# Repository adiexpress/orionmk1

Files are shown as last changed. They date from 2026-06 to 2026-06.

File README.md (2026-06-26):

Hello All who come to this project

This is the beginnings of Project O.R.I.O.N, which stands for Object Retrieval and Intelligent Operating Network

Group 1-3

ORION is a robot arm system designed to assist at a workstation. Inspired by Doctor Octopus from Spider-Man, it features a flexible tendon-driven tentacle spine arm with a 3-jaw gripper, 3 wide-angle AI cameras linked together, local voice recognition, and object detection — all running fully offline on a Raspberry Pi 5 with a Raspberry Pi AI HAT+ (Hailo-8 NPU, 26 TOPS).

The hub is a wide shallow tray (Pi and HAT side by side) keeping hub height under 1.7 inches, leaving 5.8 inches of clearance above the monitors. It detaches via a quick-release plate and runs standalone on a camera tripod from a power bank.

The spine is cable-tendon driven — 3 Dyneema UHMWPE cables (65-80lb, ~0.4mm) run through PTFE-lined channels in 9 triangular PETG segments, pulled by 3 MG996R base servos for full 3D motion. Each segment is an equilateral triangle (70mm sides, 35mm body) with M4 RC rod-end ball joints alternating 90 degrees per segment. Total reach: ~19.5 inches

The sensors that are used in this project are the FSR402 pressure sensors on the tips of the fingers of the claw

This project is driven on a few AI Models: Whisper, by OpenAI for the language transcription when a user asks a question, YOLOV8 by Ultralytics for the object tracking and detection, OpenWakeWord which is the key tool behind the "Hey ORION" activation call, and LLaVA Phi 3 for the live object description in the webcam whenever a user uses the "describe" action

Orion runs on Qwen 2.5 3B parameters version by Alibaba and essentially it is the framework for all the reasoning and computing done by the model. 

The camera system runs on 3 USB 2.0 Cameras (1080P 130 degree rotation) to help with object tracking/detection and also obstacle avoidance.
After initial calibration where the cameras are trained on distict marked locations so that they can make their distance measurements, the tri-camera system uses triangulation to gather measurements from each of the 3 FOV ranges that it has. Using this, the ORION arm has almost 360 degree FOV. 

## The Problem and our motivation to create ORION
We created this project to help future engineers, like my teammate and I, strive in the workplace when no one else is there to help. 
We built ORION because we've both been there. 
Spending late nights building something extraordinary that could change the world, but it feels like building it requires three hands. 

**ORION was made to be that 3rd hand.**

ORION is the answer to that. It acts like a personal desktop assistant that can physically help you with tasks like holding up objects, putting unnecessary tools
away, or even holding up a flashlight for those dark corners you can never see into. ORION is more than just an average robotic arm, however. It can even act as a friend. With its built-in AI voice-chat feature, you can have conversations about whatever weird things you like and it can answer the most redundant of questions. 

Many of us engineers have come to the realization that the biggest bottleneck in this field isn't knowledge or skill, but rather - its bandwidth. What my partner and I needed was a third hand that doesn't need a break, never gets tired, and doesn't complain.

## We built what we needed and we hope someone like us needs it too
<br>

## Our Motivation
<br>
Most robotics projects are built in labs, with teams with almost too large of a wallet. In contrast, ORION was built with 2 people, over nights and weekends, communicating async over schedules that seemed to never overlap
<br>
That constraint became our main idea for design, ORION had to be simple enough for two people to design and also others to easily recrate, but also powerful enough to actually keep up with our quick engineering minds 
<br>
We decided to make it run offline because we could never guarantee internet, it had to run from voice because our hands were usually always full, and we had to make it cost-effective because our budget was tight.
<br>
Every decision in this project came from a real constraint we had to come across while building it, combined with our high engineering standards
<br>

## DISCLAIMER
Due to hardware deficiency, the custom "Hey ORION" wake word has not been trained yet. The system currently uses "Hey Jarvis" (a pre-trained OpenWakeWord model). Once hardware arrives, a custom model will be trained using OpenWakeWord's training pipeline and swapped in with a single config change.
<br>

## How the pipeline works:

1. Orion starts up and greets the user
2. Orion asks the user for the wake word (in this case it will be "Hey Jarvis")
3. The user either speaks the wake word or waits until they require the assistance of Orion
4. After receiving the wake word, Orion then asks the user for a command from which they have a few preset options to choose from:
   - grab: grabs an object that must be specified by the user
   - move to: moves an object that must be specified by the user to a location
   - drop: drops the object the arm is holding in the position it is currently at
   - stow: puts the arm away into "sleep mode"
   - describe: describes the object that is in the webcam's POV
   - clarify: Orion uses this command when further clarification is necessary regarding the request
     (Ex. User says "bring me that thingy over there", Orion says "What "thingy" are you referring to?)
   - chat: A chat feature used when the user just wants a buddy to talk to or to ask general questions
   - where is: gives the location/coordinates of an object that must be specified by the user
5. User requests which ever command they require in their work and Orion parses it and fulfills the command

## AI Pipelines

| Layer | Model | Hardware it Runs On |
|---|---|---|
| Wake word | OpenWakeWord (hey_jarvis) | Pi 5 CPU |
| Transcription | Whisper tiny.en | Pi 5 CPU |
| Command parsing | Qwen2.5-coder 3B | Pi 5 CPU via Ollama |
| Object detection | YOLOv8n | Hailo-8 NPU (26 TOPS) |
| Visual Q&A | LLaVA-phi3 | Pi 5 CPU via Ollama |

---

##Build and Run Guide

### Software/Firmware setup requirements

if you haven't already: download Python (coding language used for this project<br>
<br>
(download using the link below and following the steps)<br>
'https://www.python.org/downloads/'<br>

install all python libraries and utils needed to run ORION<br>
<br>
(run this command in the Terminal CLI)<br>
'pip install -r requirements.txt'<br>

### Pull AI Models
first, install the ollama desktop app<br>
<br>
(download using the link below and following the steps)<br>
'https://ollama.com/download'<br>

after downloading:<br>
pull both AI models from ollama<br>
<br>
(run these commands in the Terminal CLI)<br>
'ollama pull qwen2.5:3b-instruct'<br>
'ollama pull llava-phi3'<br>

### Calibrate Cameras
calibrate each of the 3 camera angles (base, overhead, claw) used for this project<br>
<br>
point each camera at a flat surface with 4 known real world coordinates<br>
<br>
(run these commands in the Terminal CLI)<br>
'python calibration.py overhead'<br>
'python calibration.py base'<br>
'python calibration.py claw'<br>
<br>
then, click the 4 points in this order: top-left, top-right, bottom-left, bottom-right and press 'S' to save them<br>

### Flash Pico Firmware
1. hold BOOTSEL button on Pico while plugging into USB - mounts as a RPI-RP2 drive<br>
2. download MicroPython.uf2 from 'https://micropython.org/download/RPI_PICO/'<br>
3. drag .uf2 onto the RPI-RP2 drive -> Pico will reboot with MicroPython<br>
4. download Thonny IDE from 'https://thonny.org'<br>
5. open Thonny -> Tools -> Options -> Interpreter -> MicroPython (Raspberry Pi Pico)<br>
6. open firmware.py -> File -> Save As -> Raspberry Pi Pico -> save as 'main.py'<br>
<br>
Pico runs firmware automatically on every boot up now<br>
No compliation needed since MicroPython is interpreted<br>
No external dependencies: all libraries used are MicroPython built-ins<br>

### Add named locations (Optional)
run locations.py and input the name of the location + its coordinates to save it to ORION's memory<br>
<br>
(run this command in the Terminal CLI)<br>
'python locations.py'

### Run ORION
run orion_brain.py and let the magic begin<br>
<br>
(run this command in Terminal CLI)<br>
'python orion_brain.py<br>
<br>

To stop the processes at any time, press 'Ctrl+C'<br>
* 1st time pressing Ctrl+C will stop the voice processes
* 2nd time pressing Ctrl+C will stop the camera processes
<br>
**NOTE: this file carries alot of weight, running it may be slow, so please have some patience.**

## How to use ORION

**Basic Workflow**

## USE THESE ONLY AFTER RUNNING ALL SETUP STEPS ABOVE

1. Say **'Hey Jarvis'** - ORION wakes up and beeps
2. Say your command - if you stop talking, the 'silence detection feature' will cut you off, so make sure you have an exact command
3. ORION will then transcribe, parse, detect, and act out your command if its necessary

**Avaliable Commands:**
"grab the ____" --> ORION will find your object via camera, extend its arm and pick it up<br>
<br>
"put it in the bin" ---> ORION will move its held object into the saved position named "bin" by the user<br>
<br>
"drop it" ---> ORION will drop whatever it is holding in its current location<br>
<br>
"stow the arm" ---> ORION will fold its arm to a predetermined safe resting position<br>
<br>
"what do you see" ---> Describes its surroundings using the claw camera with LLaVA vision AI<br>
<br>
"where is my ____?" ---> returns coordinates of the named object<br>
<br>
"how do magnets work?" ---> this is just a random question, you can ask ORION things like this, and it will respond like a normal AI agent<br>
<br>
**ORION understands natural language** - for the commands above, you can phrase them in almost any way you like<br>
<br>
For commands/questions ORION does not understand, it will use the CLARIFY command, where ORION will ask the user to clarify where the misconception was made<br>
<br>
## Hardware Setup

For the shafts, please cut them according to the necessary length as you cut, as plastic expansion might change how long your shaft cuts should be.

### When 3D printing:
For ease of printing, all objects are formated as follows: "Object name xNumber of times needed." For example: "Camera Mount x2" means you must print the camera mount twice.
All objects are in PLA filament, with the exception of the parts "Claw TPU Finger," which are in TPU, and "Claw PETG Tip," which are in PETG. 
Print settings are recommended to be 15-20% infill with supports enabled and gyroid infill.

### Requirements
* All 3D printed objects 
* Drill
* CA glue and activator
* Screwdriver for m2, m3, and m4 screws
* All parts and materials dictated by the BOM
* Clippers

### Assembly overveiw
We will progress through creating ORION in the following order

1. Electronics Hub
2. Servo Hub
3. Arm
4. Claw
5. Full Assembly

Unless specified, assume the count is one per part when looking at what 3D parts to grab for a section

### Electronics Hub Assembly

Grab the Following 3D parts:
* Electronics Hub Parts 1-4
* Rectangular E-Hub Connector (2)
* Angular E-Hub Connector (2)
* Circular E-Hub Connector
* PCA9685 Mount
* Base Camera Mount
* Camera mount
* Pi Stack Mount
* Pi Stack Spacer (4)
* DC Buck Mount
* Pico Mount Top
* Pico Mount Bottom
* Power Bank Mount
* Power Bank Cover

Put together the Electronics Hub Parts (1-4) Like in the photo below. Keep in mind the holes to help you align each part with each other



Take the Circular E-Hub Connector and place it in the circular insert. Drill small holes with a small drill bit in each corner of the circle (One hole per Hub part, the hole should go through the hub part). Then put a small screw through the drilled holes (M4 or M3 both work). That circle should hold the four parts together somewhat.

Next, Take both Rectangular Connectors and use the same method to connect the Hub parts on the insert that looks like this (There should be a total of 2, on opposite sides of one another): 



Next, repeat with the Angular Connectors on the inserts that look like this (Again, total of two, on opposite sides of one another):



After that, we will move on to assembling our electronics.

Take your Pi 5, AI PI 5 HAT, Respeaker, 40 pin extended stacking header, Pi stack mount, and the mounting hardware that comes with the AI HAT+ . 

Attach the extended stacking header onto the pins for the Pi 5. Take an M3 screw, and stick it through the bottom of the stack mount and through the pi %, screwing it into the 4 Pi stack Spacers. Here is what it should look like:



Attach the AI Pi HAT+ and use M3 screws to attach it to the spacers like so:



Attach the respeaker on top of that to make it look like this:



After that, place the pico inside its case like so:



The PCA9685 like so:



The Buck convertor like so:



and The Camera like so:



After that, please wire all of your electronic components (excluding the speaker, the servos, the other 2 cameras, and the FSR sensors) like so:



Please use jumber cables, USBA, USBC, And USB Pigtails as necessary. If you need more assistance, please take a look at an unofficial version below:



Attach that entire system like so, making sure to use either M3 or M4 screws and their assorted heatset insert:



Please attach the Power Bank Mount like so:



And once you place the power bank inside place the cover like so, making sure to use heatset inserts:



you can add the speaker into the slot using CA glue and the camera right above that in the premade holes:



Finally, use zipties and the cable tie holders to organize your wires. Please use CA glue and activator to attach the cable tie holders.

### Servo Hub Assembly:

Once you are confident your electircal wiring is correct, gather the following:

* Electronic Hub Top A-D
* E-Hub Rectangular Connector (2)
* Gear to Servo Mount
* Rotator A (3)
* Servo winch (3)
* Servo Hub Sides A-C
* Servo Hub Side Connector (6)
* Servo Hub Top
* Winch Pulley (6)
* Small Gear
* Susan Gear
* Overhead Camera Mount

Assemble the Electornic Hub Tops (A-D) and Overhead Camera Mount like so (with heatset inserts): 



Use E-Hub E-Hub Rectangular Connectors in the same method as before, like so:



Attach all of that onto the Electronics Hub (With heatset inserts):



Attach the packaged long servo horns and the 3D pritned Rotator A's to an MG90S servo, and clip off the excess from the servo horn till you have 3 MG90S servos that look like this:



Then, take an MG996R servo at attach it here, using headset inserts:



Then attach the small gear to that servo using the Gear to Servo mount.

Using spacers and screws, attach the outer ring of the lazy susan to the assembly like so:



Attach the Susan gear atop that:



Attach Servo Hub sides A-C using the 6 servo side connectors like before, 3 MG996R servos, 3 winch pulleys, and three Servo Winches to construct this (use heatset inserts and attach the servos before attaching the siding):



Attach the bottom:



screw that into the susan gear



Attach the servo hub Top to make it look like so:



Finally, attach the MG90S servos from before like so:



### Arm Assembly

Grab the following 3D printed parts:

* Middle Segment (6)
* Outer Pin Stopper (14)
* Pin to Rod end Spacer (14)
* Rod End Spacer (7)
* Servo Hub Cap

To stat off, take a rod end, a 3mm shaft, and two pin to rod end spacers and assemble them like so:



Take the Outer Pin Stopper and put it on the outsides to stop the pin from sliding out (screw or CA glue)

Attach the servo Hub Cap to have this:



Momentarialy put that to the side and grab your Middle segments. Take your Rod End spacer and attach it here:



put a rod end beneath it and screw the rod end spacer into that, with the bottom of the middle segment in between. Repeat for every middle segment.
Now take the pins, the outer pin stoppers, and the Pin to Rod end Spacers to take the rod end from the bottom of one middle segment at attach it to the top of another. However, you will notice there are two sets of holes, so make sure to alternate which set you put the pin through.

You will have a set of connected segments looking like this:



Take two sets of Dyneema tubing and thread it through two sets of PTFE tubing. Repeat 3 times and put one set through each of the three outer holes of every mid segment.

### Claw Assembly

You will need your remaining 3D printed parts

Take your 5mm shafts and slide it through the holes of the Main Fairlead body. screw in the Fairlead Pin holders like so:



Repeat until you have 9 of these.

Add one Camera here:



and the Claw Camera Holder on top of it:



Attach the 3 spring holders like so:



slide a 5mm shaft through each of these holes:



Attach 3 fairleads like so:



Assemble the Claw by inserting 4 (two on each side) TPU connector pins into the Claw TPU finger, using CA glue to attach them to the Claw Finger A part and the Claw PETG part, like so:



Repeat 3 times

Undo the 5mm shaft from before and slide the claw fingers through like so:



and cover each side with the Claw pin stoppers, using CA glue or screws to attach:



Attach 3 fairleads on the bottom like this:


On each claw, drill a wider hole through the small pre-printed one and pass the FSR sensor wiring through that. Then attach the fsr sensors and the FSR wire holder (with screws) like so:



Attach claw base A with heatset inserts and screws like so:



Attach remaining fairleads like so:



Then Attach claw base B like so, making sure to put a Rod End Spacer through its center and attach a rod end before screwing it into the claw system with heatset inserts.



Take one set of the ptfe tubing and attach it to the claw finger where the hole is made, and take the other set and tie a knot to once they both go through all the middle segments. At the bottom, connect the tubing from the fingers and connect it to the winch on the MG90S servo and take the other three and connect it to the MG996R servo winches (through the center hole of the servo hub) This is the tensioning that will control the arm.

Once you attach that to the rest of the parts (from the last segment of the arm, using the same technique with the spacers to attach the rod end bearing as before), you can run the wires from the FSR sensors down into the E-Hub and make sure your wiring matches this diagram, using cable tie mounts as needed.


or the unofficial one if that is what you prefer, as it is simpler.



Finally, you will have a finished ORION:



## Wiring

Although already listed in the build guide, we thought it might be helpful to add the wiring image here for easy referral.



## BOM:

* FSR Sensor
* Steel Extension
* Plastic Rod-Ends
* MG90S
* Fishing Line (65 LBS @ 300 YDS
* USB Cameras
* Buck/Voltage Resistor
* 65W Power Bank
* PWM Servo Driver
* Raspberry Pi Pico (RP2040 Microcontroller)
* Female-Female Jumper Wires
* 1-3 Connector
* 1-2 Connector
* External Speaker
* Raspberry Pi Pico Headers
* Raspberry Pi 5 Headers
* Lazy Susan
* AI HAT+ with Hailo-8 NPU
* External Mic for Pi
* Raspberry Pi 5
* M2, M3, M4 Screws
* M2, M3, M4 Screw Heat-set inserts
* Screw spacers
* Cable-tie mounts
* PTFE Tubing
* 10K Ohm Resistors
* USB-A to USB-A Cable
* USB-C to USB-C Cable
* USB-A Male to 2-Pin Pigtail exposed cable
* CA glue and activator
* 5mm Shafts
* 3mm Shafts
* PLA Filament
* TPU Filament
* PETG Filament

[BoM - Sheet1.csv](https://github.com/user-attachments/files/29170802/BoM.-.Sheet1.csv)

---
Thank you so much for checking out O.R.I.O.N!

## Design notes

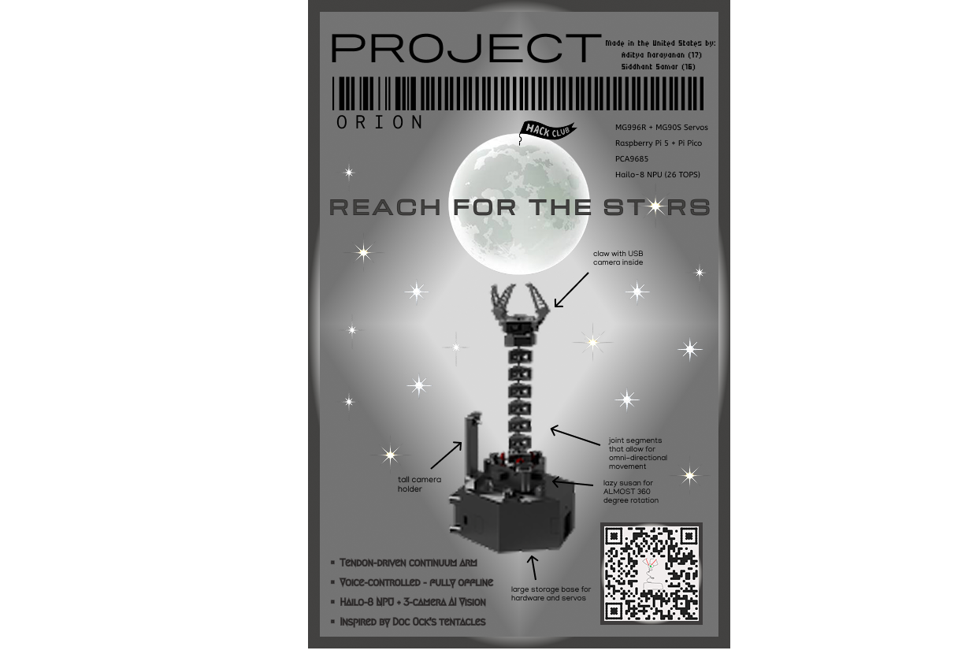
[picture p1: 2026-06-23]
Docs/Zine.png

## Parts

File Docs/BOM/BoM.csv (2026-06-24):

Part | Description | Quantity | Unit Price($) | Total Price($) | Purchase Link
Elecbee Interlink FSR402 Force Sensing Resistor Thin Film Force Sensor 0g-10kg for Arduino UNO R3 Robotics | FSR Sensor | 3 | 2.54 | 7.62 | https://www.elecbee.com/en/product-detail/fsr402-force-sensitive-resistor-0-5-inch-fsr-pressure-sensor-module-diy-kit_25461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
RS PRO 821425 Stainless Steel Extension Spring 25mm Free Length 5mm OD 5.4N Tension | Steel Extension Spring | 1 | 4.13 | 4.13 | https://us.rs-online.com/product/rs-pro/821425/73234297/
RC4WD M3/M4 Plastic Long Rod Ends (20) | Plastic Rod Ends | 1 | 8.99 | 8.99 | https://store.rc4wd.com/RC4WD-M3M4-Plastic-Long-Rod-Ends-20_p_4477.html
MG90S Servo 1/4/10 Pcs Metal Gear Digital 9g Servo For RC Helicopter Airplane Boat Car RC Robot | MG90S Servos | 4 | 2.64 | 10.56 | https://www.aliexpress.us/item/3256807336350998.html?src=google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
Reaction Tackle Braided Fishing Line - NO FADE Black (65LBS 300YDS) | Fishing Line (65LBS 300YDS) | 1 | 17.98 | 17.98 | https://reactiontackle.com/products/reaction-tackle-braided-fishing-line-no-fade-black?variant=44287187419375
1080P HD Fixed Focus USB Camera Module 130 Degree Wide Angle for 3D Printer Free Drive 2MP Mini Cam UVC OTG for Linux Window | USB Cameras | 3 | 9.04 | 27.12 | https://www.aliexpress.us/item/3256811583689166.html?gatewayAdapt=glo2usa4itemAdapt
DROK DC Buck Converter Adjustable Voltage Regulator 12V 6V-32V to 1.5-32V 5A, LCD Screen Step Down Converter with USB Port and Protective Case | Buck/Voltage Regulator | 1 | 15.99 | 15.99 | https://www.amazon.com/DROK-Adjustable-Converter-Transformer-Protective/dp/B07JZ2GQJF?th=1
Techsmarter 20000mah 65W PPS USB-C PD Power Bank with Samsung Super Fast Charging. Laptop Portable Charger Compatible with iPhone, Galaxy, Android, iPad, MacBook, Chromebook, XPS, ThinkPad, Spectre | 65W Power Bank | 1 | 59.99 | 59.99 | https://www.walmart.com/ip/Techsmarter-20000mah-65W-PPS-USB-C-PD-Power-Bank-Samsung-Super-Fast-Charging-Laptop-Portable-Charger-Compatible-iPhone-Galaxy-Andro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
Adafruit 16-Channel 12-bit PWM/Servo Driver - I2C interface - PCA9685 | PWM Servo Driver | 1 | 14.95 | 14.95 | https://www.adafruit.com/product/815
2Pcs Raspberry Pi Pico Development Board, Raspberry Pi RP2040 Dual-core ARM Cortex M0+ Processor, Running Up to 133 MHz, Support C/C++/Python, 2MB Quad SPI Flash Integrated with SPI/I2C/UART Interface | Raspberry Pi Pico with RP2040 Microcontroller | 1 | 14.59 | 14.59 | https://www.amazon.com/Raspberry-Pi-Pico-Development-Integrated/dp/B0BDLHMQ9C
40pcs 20 cm (8 inch) Female to Female Multicolored Dupont Wire Breadboard Jumper Ribbon Cables Compatible with Arduino Projects(F/F) | Female-to-Female Jumper wires | 1 | 3.99 | 3.99 | https://www.amazon.com/California-JOS-Breadboard-Optional-Multicolored/dp/B0BRTJQGS6
1 in 2/3/4/5 out Quick Splicing Mini Compact Connector Orange/Yellow/Blue Lever Push-in Terminal Block For Electrical Connection | 1 to 3 Connector | 1 | 4.22 | 4.22 | https://www.aliexpress.us/item/3256806243155519.html?src=google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
1 in 2/3/4/5 out Quick Splicing Mini Compact Connector Orange/Yellow/Blue Lever Push-in Terminal Block For Electrical Connection | 1 to 2 Connector | 1 | 3.47 | 3.47 | https://www.aliexpress.us/item/3256806243155519.html?src=google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
Wired External Speaker, Speaker, Mini Speaker, Portable 13.12ft Black For | External Speaker | 1 | 13.52 | 13.52 | https://www.walmart.com/ip/Wired-External-Speaker-Speaker-Mini-Speaker-Portable-13-12ft-Black-For/1761308510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
SparkFun Electronics 17907 Raspberry Pi Pico Headers Kit | RASPBERRY PI PICO HEADERS KIT | 1 | 1.59 | 1.59 | https://www.digikey.com/en/products/detail/sparkfun-electronics/17907/13910058?gclsrc=aw.ds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
Stacking Header - 2x20 Extra Tall Header - for Pi A+/B+/Pi 2/Pi 3/Pi 4/Pi 5 | Raspberry Pi 5 Headers | 1 | 2.95 | 2.95 | https://www.adafruit.com/product/1979#technical-details
Aluminum Heavy Duty Lazy Susan Rotating Turntable Bearing Swivel Plate Hardware for Dining-Table (10 inch) | Lazy Susan | 1 | 19.99 | 19.99 | https://us.amazon.com/Dailydanny-Aluminum-Rotating-Turntable-Dining-Table/dp/B07SZ87WSM
Raspberry Pi AI Hat 26 Tops | AI HAT for Hailo-8 NPU | 1 | 109.99 | 109.99 | https://www.microcenter.com/product/687348/raspberry-pi-ai-hat-26-tops
reSpeaker 2-Mics Pi HAT V2.0 for Raspberry Pi - TLV320AIC3104 Audio Codec, 2 Analog Microphones, 3 APA102 RGB LEDs, 3.5mm Audio Jack, User Button, attached with NLU software algorithms, VAD,DOA, KWS | Mic for Pi | 1 | 13.99 | 13.99 | https://www.seeedstudio.com/ReSpeaker-2-Mics-Pi-HAT.html
Raspberry Pi 5 8GB | Raspberry Pi 5 | 1 | 175 | 175 | https://www.canakit.com/raspberry-pi-5-8gb.html
1290-Piece M2, M3, M4, M5 Stainless Steel Button Head Hex Socket Screw Kit with Nuts, Washers and Lock Washers | M2, M3, M4 Screws | 1 | 22.72 | 22.72 | https://www.homedepot.com/p/MYWISH-1290-Piece-M2-M3-M4-M5-Stainless-Steel-Button-Head-Hex-Socket-Screw-Kit-with-Nuts-Washers-and-Lock-Washers-SF-TZ00005/33433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
M2 M3 M4 Heat Set Insert 3d Printing Soldering Iron Tip Machine Screw and Brass Threaded Inserts Nut Bolt Tool Kit Game Computer | M2, M3, M4 Heat-set inserts | 1 | 20.19 | 20.19 | https://www.walmart.com/ip/365Pack-M2-M2-5-M3-M4-M5-Metric-Threaded-Inserts-Brass-Heat-Set-Insert-Knurled-Nuts-Assortment-Kit-3D-Printing-Female/15199112905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
345 Pcs Black Nylon Electrical Outlet Spacers Kit - Non-Threaded Round Plastic Spacers for Switch & Receptacle Screws, Secure Fit Spacer Assortment for Outlet Installation | Spacers | 1 | 6.95 | 6.95 | https://www.amazon.com/Spacers-Assortment-Electrical-Unthreaded-Receptacle/dp/B0CBBC9SR1
Cable Tie Mounts, (100-Pieces), White | Cable tie mounts | 1 | 2.95 | 2.95 | https://www.homedepot.com/p/QualGear-Cable-Tie-Mounts-100-Pieces-White-CM2-W-100-P/303357753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
PTFE Teflon tubing 10ft - 3mm ID X 4mm OD for 1.75 Filament Bowden 3D Printer - Allen Tech PTFE Teflon Tube | PTFE Tubing | 1 | 8.99 | 8.99 | https://www.amazon.com/s?k=ptfe+tubing+3mm
Through-Hole Resistors - 10K ohm 5% 1/4W - Pack of 25 | 10k Resistors | 1 | 0.75 | 0.75 | https://www.adafruit.com/product/2784
Monoprice USB 2.0 Cable - 1.5 Feet - White | USB Type-A Male to USB Type-A Male, 28/24AWG, Gold Plated, 480 Mbps | USB-A to USB-A Cable | 1 | 6.58 | 6.58 | https://www.target.com/p/monoprice-usb-2-0-cable-1-5-feet-white-usb-type-a-male-to-usb-type-a-male-28-24awg-gold-plated-480-mbps/-/A-76798684
Anker Braided USB-C to USB-C Cable (6ft, 60W) Black | USB-C to USB-C Cable | 1 | 7.97 | 7.97 | https://www.walmart.com/ip/Anker-322-Braided-USB-C-to-USB-C-Cable-6ft-A81F6H11-1-Black/2387232905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
USB Power Pigtail Cable USB Male to 2 Pin Bare Wire Open End Power Pigtail Cord for LED Fan Camera Accessories | USB-A Male to 2 Pin pigtail cable | 1 | 5.67 | 5.67 | https://www.walmart.com/ip/USB-Power-Pigtail-Cable-USB-Male-to-2-Pin-Bare-Wire-Open-End-Power-Pigtail-Cord-for-LED-Fan-Camera-Accessories/18017062155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
Adhesive Guru AG250 CA Glue With Activator | CA glue and activator | 1 | 11.99 | 11.99 | https://www.hobbylobby.com/crafts-hobbies/glue-adhesives/liquid-craft-glue/adhesive-guru-ag250-ca-glue-with-activator/p/81250141
5mm Shaft (Stainless Steel, 250mm Length) | 5mm shaft | 2 | 4.29 | 8.58 | https://www.servocity.com/5mm-x-250mm-stainless-steel-precision-shafting/
Uxcell 2 Pcs Round Steel Rod 3mm Diameter HSS Lathe Bar Stock Tool 200mm Long for Shaft Gear Drill Lathes Boring Machine Turning Miniature Axle Cylindrical Pin DIY Craft Tool | 3mm shaft | 1 | 10.19 | 10.19 | https://www.walmart.com/ip/Uxcell-2-Pcs-Round-Steel-Rod-3mm-Diameter-HSS-Lathe-Bar-Stock-Tool-200mm-Long-Shaft-Gear-Drill-Lathes-Boring-Machine-Turning-Miniat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
Ender-PLA Filament 2KG Value Pack | PLA Filament | 1 | $19.80 | $19.80 | https://store.creality.com/products/live-ender-pla-filament-2kg-value-pack?variant=51937720336749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
Inland 1.75mm TPU 3D Printer Filament 1.0 kg (2.2 lbs.) Spool - Black | TPU Filament | 1 | 24.99 | 24.99 | https://www.microcenter.com/product/610047/inland-175mm-black-tpu-3d-printer-filament---1kg-spool-(22-lbs)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
Inland 1.75mm PETG 3D Printer Filament 1kg Carboard Spool (2.2 lbs) - Black | PETG Filament | 1 | 12.99 | 12.99 | https://www.microcenter.com/product/503745/175mm_petg_3d_printer_filament_1kg_carboard_spool_(22_lbs)_-_black_dimensional_accuracy_--_003mm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
TOTAL |  | 43 |  | 701.94

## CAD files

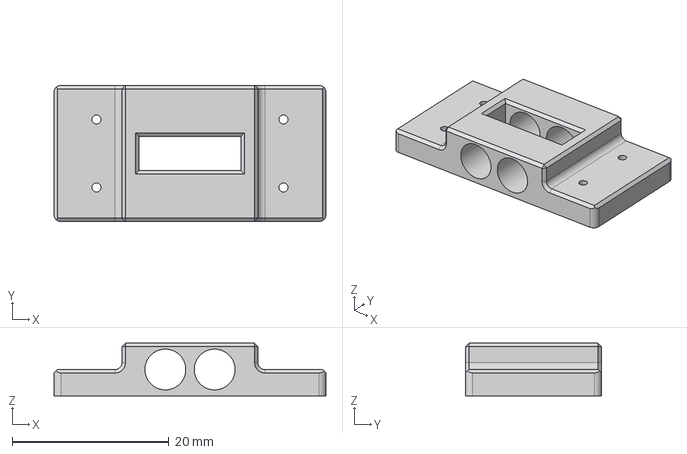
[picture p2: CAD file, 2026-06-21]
CAD/Parts/Main_Fairlead_Body_x9.step
34.7 x 17.3 x 6.72 mm

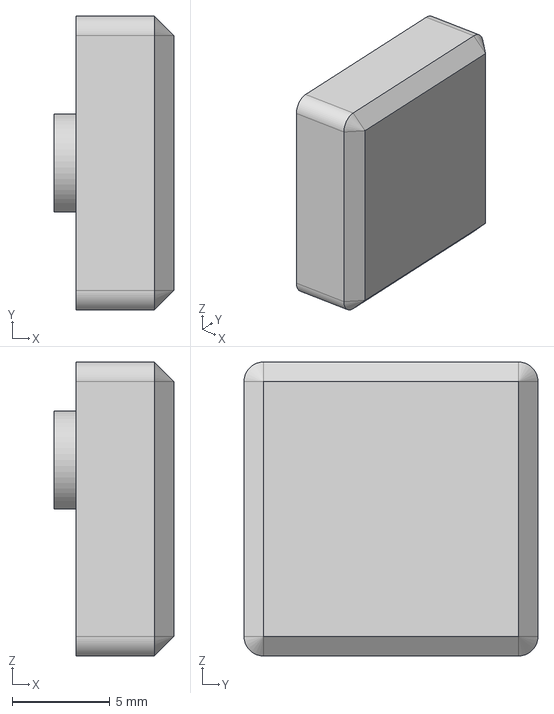
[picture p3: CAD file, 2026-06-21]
CAD/Parts/Claw_Pin_Stopper_x6.step
6.12 x 15.0 x 15.0 mm

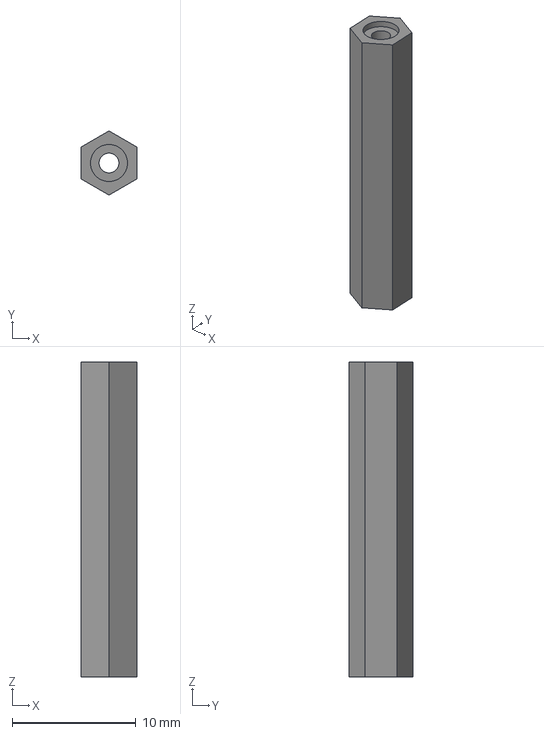
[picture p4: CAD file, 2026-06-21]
CAD/Parts/Pi_Stack_Spacer_x4.step
4.50 x 5.20 x 25.5 mm

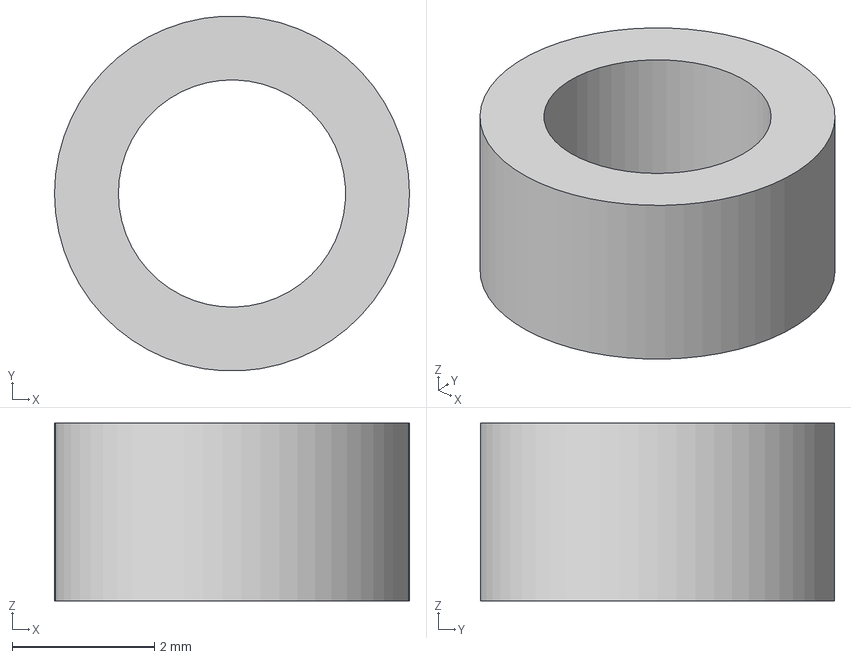
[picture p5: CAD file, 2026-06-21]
CAD/Parts/Pin_to_Rod_end_Spacer_x14.step
5.00 x 4.99 x 2.50 mm

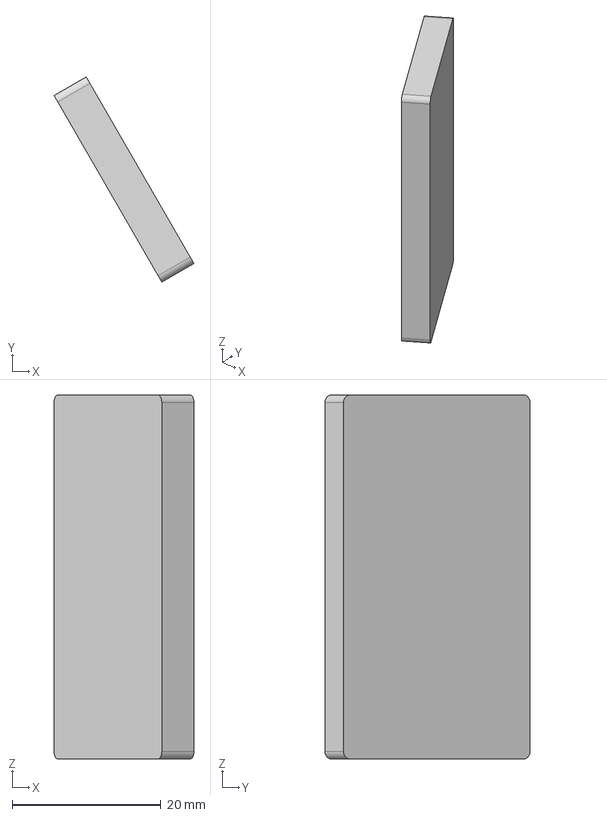
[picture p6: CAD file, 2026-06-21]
CAD/Parts/Rectangular_E-Hub_Connector_x2.step
18.8 x 27.6 x 49.0 mm

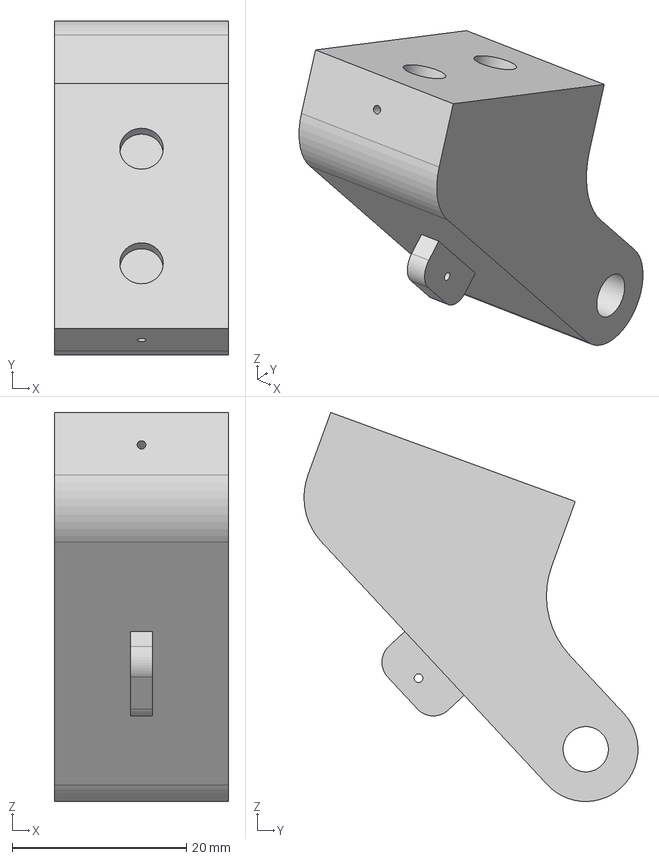
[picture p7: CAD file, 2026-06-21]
CAD/Parts/Claw_Finger_A_x3.step
20.0 x 38.3 x 44.6 mm

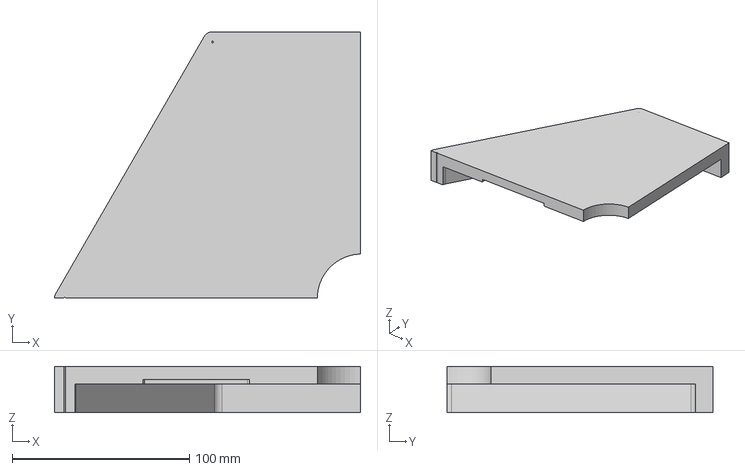
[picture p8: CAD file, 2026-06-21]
CAD/Parts/Electronic_Hub_Top_D_x1.step
172.4 x 150.0 x 26.2 mm

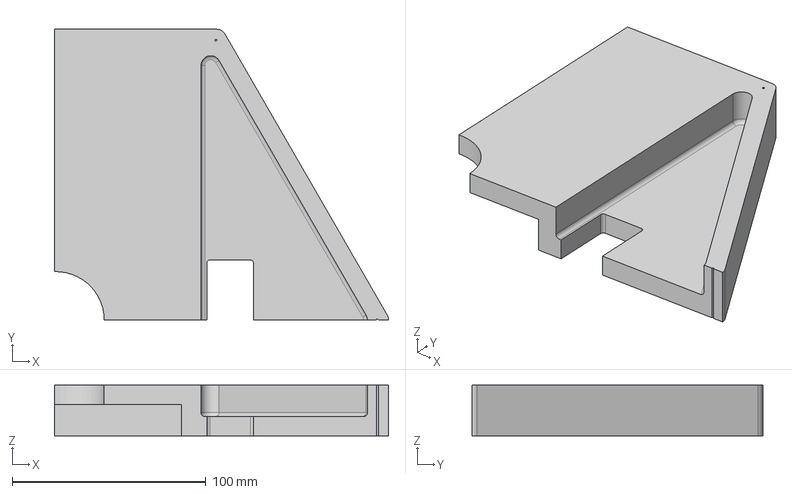
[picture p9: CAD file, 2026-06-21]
CAD/Parts/Electronic_Hub_Top_A_x1.step
172.4 x 150.0 x 26.2 mm

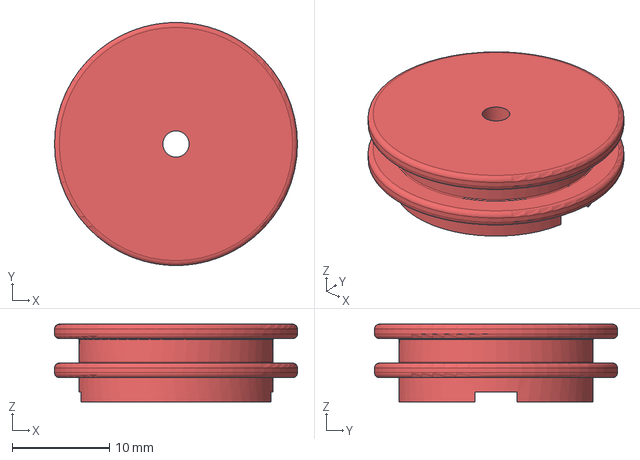
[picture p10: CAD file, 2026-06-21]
CAD/Parts/Rotator_A_x3.step
25.0 x 25.0 x 8.00 mm

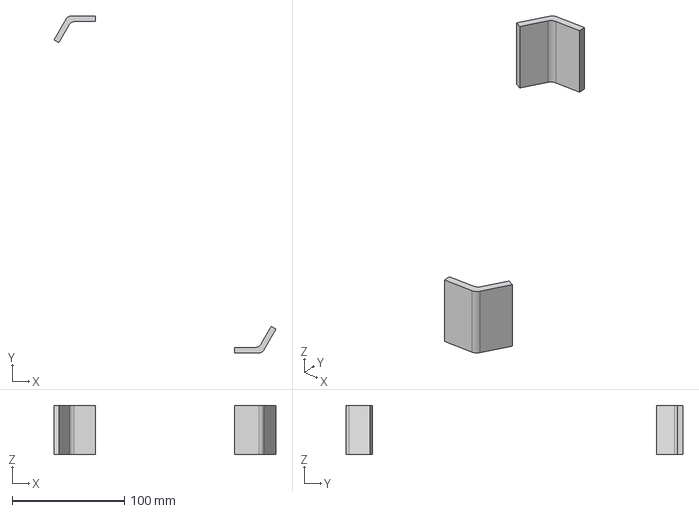
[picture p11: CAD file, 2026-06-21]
CAD/Parts/Angular_E-Hub_Connector_x2.step
197.7 x 300.0 x 44.0 mm

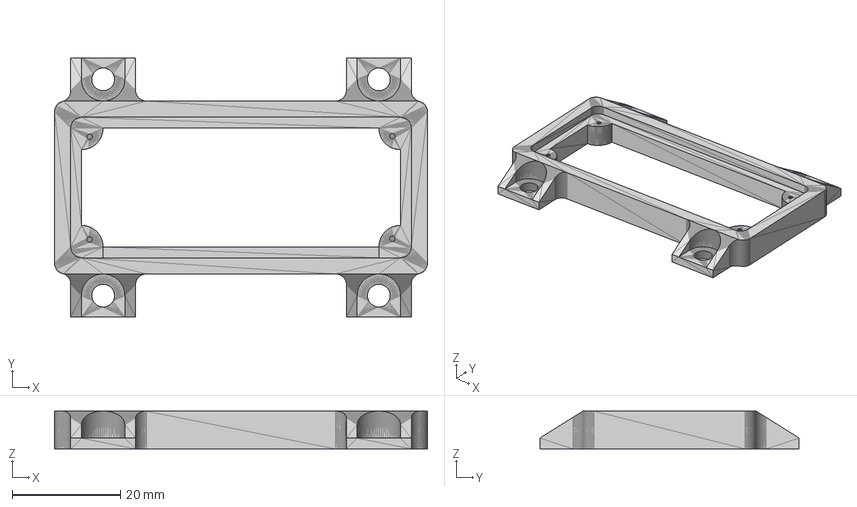
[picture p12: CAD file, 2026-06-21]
CAD/Parts/PCA9685_Mount_x1.step
69.0 x 48.0 x 7.00 mm

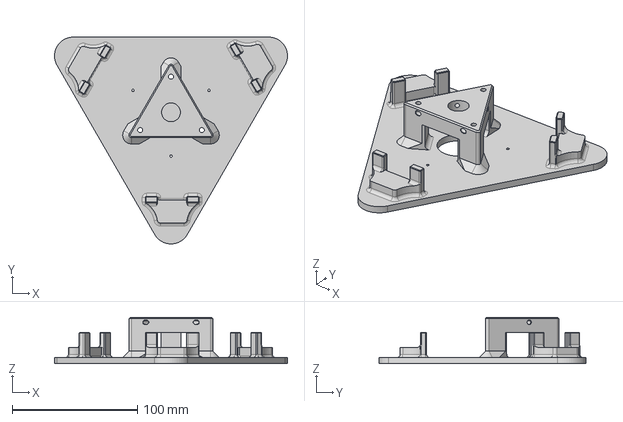
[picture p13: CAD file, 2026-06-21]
CAD/Parts/Servo_Hub_top_x1.step
185.9 x 165.0 x 37.0 mm

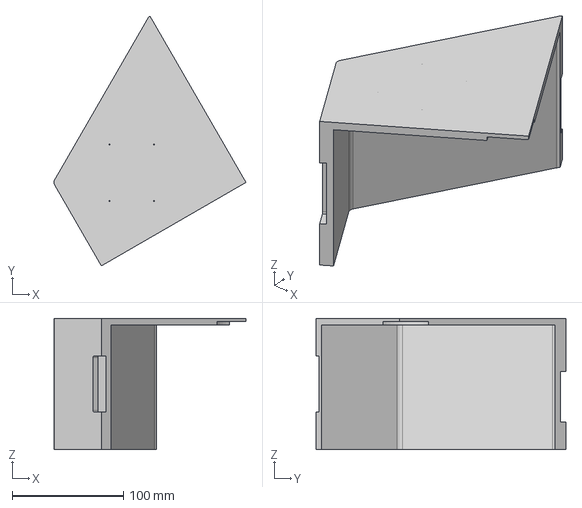
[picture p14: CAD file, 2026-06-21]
CAD/Parts/Electronics_Hub_Part1_x1.step
172.4 x 224.3 x 117.9 mm

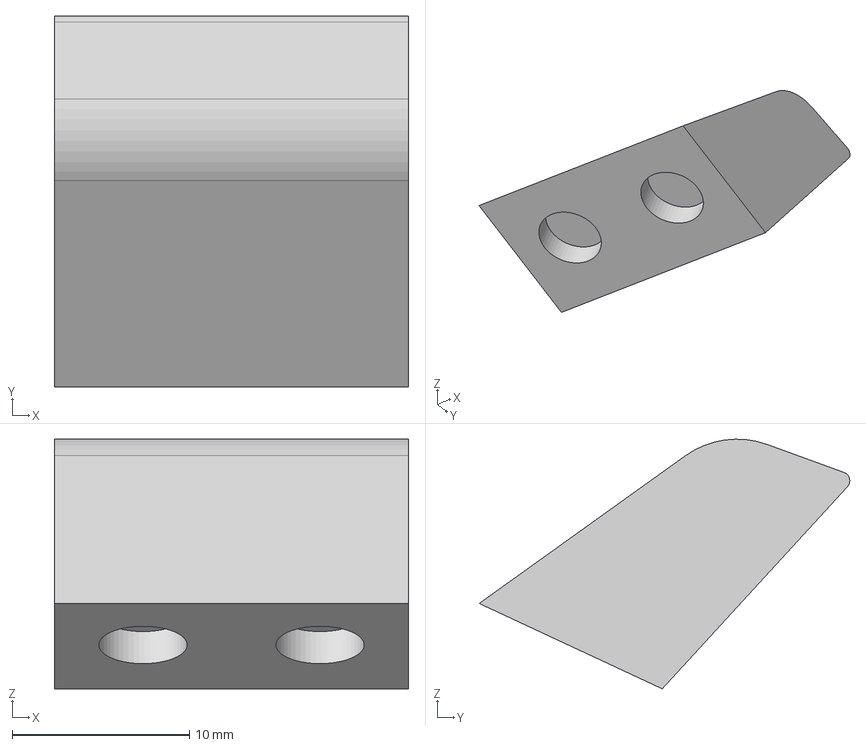
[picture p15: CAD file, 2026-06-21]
CAD/Parts/Claw_PETG_Tip_x3.step
20.0 x 20.9 x 14.1 mm

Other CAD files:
CAD/Parts/Middle_Segment_x6.step
CAD/Parts/FSR_Wire_Holder_x3.step
CAD/Parts/Servo_Hub_Side_Connector_x6.step
CAD/Parts/E-Hub_Rectangular_Connector_x2.step
CAD/Full/Full_ORION.f3z
CAD/Parts/Base_Camera_Mount_x1.step
CAD/Parts/Camera_mount_x2.step
CAD/Parts/Circular_E-Hub_Connector_x1.step
CAD/Parts/Claw_Base_A_x1.step
CAD/Parts/Claw_Base_B_x1.step
CAD/Parts/Claw_Base_C_x1.step
CAD/Parts/Claw_Camera_Holder_x1.step
CAD/Parts/Claw_TPU_Finger_x3.step
CAD/Parts/DC_Buck_Mount_x1.step
CAD/Parts/Electronic_Hub_Top C_x1.step
CAD/Parts/Electronic_Hub_Top_B_x1.step
CAD/Parts/Electronics_Hub_Part2_x1.step
CAD/Parts/Electronics_Hub_Part3_x1.step
CAD/Parts/Electronics_Hub_Part4_x1.step
CAD/Parts/Fairlead_Pin_Holder_x18.step
CAD/Parts/Gear_to_Servo_mount_x1.step
CAD/Parts/Outer_pin_Stopper_x14.step
CAD/Parts/Overhead_Camera_Mount_x1.step
CAD/Parts/Pi_Stack_Mount_x1.step
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

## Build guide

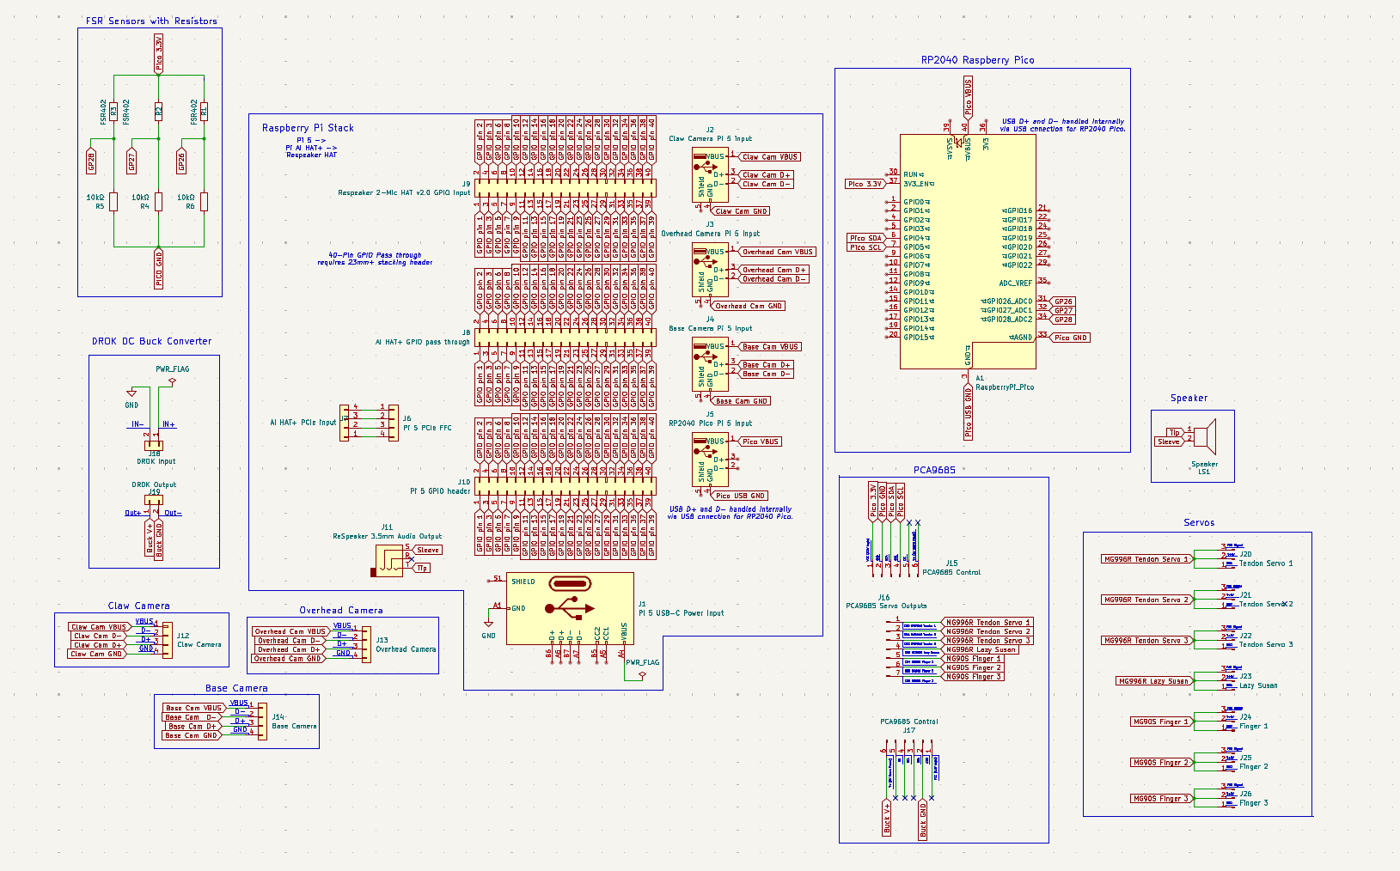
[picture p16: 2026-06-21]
Wiring/Wiring_Schematic.png

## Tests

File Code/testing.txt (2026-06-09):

GRAB ACTION:
-1.
Command: 'grab my phone'
Parsing: 'grab my phone'
raw output: {"action":"grab","target":"phone","coordinates":[null],"claw_force":0.6}
[ORION]: Grabbing phone
[GRAB] target = phone coords = [2.4, 6.0] force = 0.6

-2.
Command: 'grab my water bottle'
Parsing: 'grab my water bottle'
raw output: {"action":"grab","target":"water bottle","coordinates":[null],"claw_force":0.6}
[ORION]: I can't see your water bottle right now
[GRAB] target = water bottle coords = None force = 0.6

-3. 
Command: 'fetch my phone.'
Parsing: 'fetch my phone.'
raw output: {"action":"grab","target":"phone","coordinates":[null],"claw_force":0.6}
[ORION]: Grabbing phone
[GRAB] target = phone coords = [2.4, 6.0] force = 0.6

MOVE TO ACTION
-1.
Command: 'move it to the bin.'
Parsing: 'move it to the bin.'
raw output: {"action":"move_to","location":"bin","coordinates":[16.0,1.0]}
[ORION]: Moving object to bin
[MOVE] location = bin coords = [27.0, 19.6]

-2.
Command: 'move it to the trash can.'
Parsing: 'move it to the trash can.'
raw output: {"action":"move_to","location":"trash can","coordinates":[16.0,1.0]}
[ORION]: I don't know where trash can is
[CLARIFY] I don't know where trash can is

-3. 
Command: 'take it to the bin'
Parsing: 'take it to the bin'
raw output: {"action":"move_to","location":"person","coordinates":[16.0,1.0]}
[ORION]: I don't know where person is
[CLARIFY] I don't know where person is

DROP ACTION:

-1.
Command: 'drop it'
Parsing: 'drop it'
raw output: {"action":"drop"}
[ORION]: dropping object
[DROP] dropping object

-2.
Command: 'drop there right here.'
Parsing: 'drop there right here.'
raw output: {"action":"move_to","location":"there right here","coordinates":[16.0,1.0]}
[ORION]: I don't know where there right here is
[CLARIFY] I don't know where there right here is

STOW ACTION:

-1.
Command: 'stow your arm.'
Parsing: 'stow your arm.'
raw output: {"action":"stow"}
[ORION]: Stowing arm
[STOW] stowing arm

-2.
Command: 'put your arm away'
Parsing: 'put your arm away'
raw output: {"action":"stow"}
[ORION]: Stowing arm
[STOW] stowing arm

DESCRIBE ACTION (with webcam)(takes long time to answer)

(correct answer: a person with dark hair and dark features, black tank top, gold earrings in both ears + gold chain, handsome :)

-1.
Command: 'what do you see in the webcam right now?'
Parsing: 'what do you see in the webcam right now?'
raw output: {"action":"describe","query":"what do you see in the webcam right now?"}
[ORION]: Let me take a look
[ORION]: In the image, a young man is sitting on a chair with his mouth closed. He has dark hair and is wearing earrings in both ears. His attire consists of a black tank top and a gold chain necklace. A red book can be seen behind him, along with some other items including a white cord. The room he's in has a window, suggesting it could be daytime outside.
[DESCRIBE] In the image, a young man is sitting on a chair with his mouth closed. He has dark hair and is wearing earrings in both ears. His attire consists of a black tank top and a gold chain necklace. A red book can be seen behind him, along with some other items including a white cord. The room he's in has a window, suggesting it could be daytime outside.'

-2. Command: 'describe the webcam.' 
Parsing: 'describe the webcam.'
raw output: {"action":"chat","response":"The webcam is located on the desk."}
[ORION]: The webcam is located on the desk.
[CHAT] The webcam is located on the desk.

(showing iphone to the camera and asking orion to tell me what object it is)

-3.
Command: 'can you tell me what this object is?'
Parsing: 'can you tell me what this object is?'
raw output: {"action":"describe","query":"what is this?"}
[ORION]: Let me take a look
[ORION]: The image is a black and white photograph that captures a close-up view of an object in the shadows. The subject appears to be dark and indistinct, with only its edge faintly visible due to the contrast between it and the surrounding darkness. The background presents a stark, empty expanse devoid of any discernible features or objects.
The overall composition of the image is simple yet evocative, creating an atmosphere of mystery and intrigue. The absence of color focuses the viewer's attention on the shapes and textures within the frame, while the play of light and shadow adds depth and dimension to the scene.
As for identifying the specific subject in the image, it is challenging due to its indistinct nature and limited visibility. It could potentially be a person or an animal, but without further context or details, it's impossible to confidently determine what the subject represents.

-4.
Command: 'what object am i holding right now?'
Parsing: 'what object am i holding right now?'
raw output: {"action":"describe","query":"what object am i holding right now?"}
[ORION]: Let me take a look
[ORION]: If I'm looking at a screen with a black background, there would be no objects to hold. However, if we're talking about the photo itself, you can see your hand holding a phone in the image. The background of the image is black as well, which makes it difficult to discern what lies beneath.
[DESCRIBE] If I'm looking at a screen with a black background, there would be no objects to hold. However, if we're talking about the photo itself, you can see your hand holding a phone in the image. The background of the image is black as well, which makes it difficult to discern what lies beneath.'

CLARIFY ACTION (NEED TO FIX!!)

-1.
Command: 'uh, how do i solve this thing over here?'
Parsing: 'uh, how do i solve this thing over here?'
raw output: {"action":"clarify","message":"did you mean to ask how to solve a problem on your desk?"}
[ORION]: did you mean to ask how to solve a problem on your desk?
[CLARIFY] did you mean to ask how to solve a problem on your desk?

-2.
Command: 'can you clarify this for me?'
Parsing: 'can you clarify this for me?'
raw output: {"action":"clarify","message":"did you mean to clarify something in the current world state?"}
[ORION]: did you mean to clarify something in the current world state?
[CLARIFY] did you mean to clarify something in the current world state?

uses describe too much when it should be using clarify (need to differeniate more)

CHAT ACTION:

-1. 
Command: 'how do i solve this rubik's cube?'
Parsing: 'how do i solve this rubik's cube?'
raw output: {"action":"chat","response":"Solving a Rubik's Cube involves several steps including identifying the color of each face and solving one layer at a time using algorithms. Would you like to know more about specific algorithms or techniques?"}
[ORION]: Solving a Rubik's Cube involves several steps including identifying the color of each face and solving one layer at a time using algorithms. Would you like to know more about specific algorithms or techniques?
[CHAT] Solving a Rubik's Cube involves several steps including identifying the color of each face and solving one layer at a time using algorithms. Would you like to know more about specific algorithms or techniques?

-2.
Command: 'do you like tiktok?'
Parsing: 'do you like tiktok?'
raw output: {"action":"chat","response":"I am a robotic arm assistant and do not have preferences or emotions like humans. How can I assist you today?"}
[ORION]: I am a robotic arm assistant and do not have preferences or emotions like humans. How can I assist you today?
[CHAT] I am a robotic arm assistant and do not have preferences or emotions like humans. How can I assist you today?

-3
Command: 'how does the world work?'
Parsing: 'how does the world work?'
raw output: {"action":"chat","response":"The world works through a complex system of physical laws and principles that governs everything from atoms to galaxies."}
[ORION]: The world works through a complex system of physical laws and principles that governs everything from atoms to galaxies.
[CHAT] The world works through a complex system of physical laws and principles that governs everything from atoms to galaxies.

WHERE IS ACTION:

-1. 
Command: 'where's the bin?'
Parsing: 'where's the bin?'
raw output: {"action":"where_is","target":"bin"}
[ORION]: bin is at [27.0, 19.6]
[WHERE IS] target = bin coords = [27.0, 19.6]

-2.
Command: 'where's my phone?'
Parsing: 'where's my phone?'
raw output: {"action":"where_is","target":"phone"}
[ORION]: phone is at [2.4, 6.0]
[WHERE IS] target = phone coords = [2.4, 6.0]
Current world state: ['person']

-3.
Command: 'where's my rubik's cube?'
Parsing: 'where's my rubik's cube?'
raw output: {"action":"where_is","target":"rubik's cube"}
[ORION]: No rubik's cube location saved
[WHERE IS] target = rubik's cube coords = None

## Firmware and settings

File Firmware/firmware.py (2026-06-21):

#firmware Orion
#runs on raspberry pi rp2040
#sends json commands from pi 5 at 115200 baud
#rp2040 controls all servos via PCA9685
#reads fsr sensors through ADC pins

 # Full command set:

    # TENDON SERVOS (3x MG996R):
    # {"cmd": "tendon", "cable": 0, "angle": 90} --------> moves one tendon servo

    # LAZY SUSAN (1x MG996R):
    # {"cmd": "rotate", "angle": 90}. ------> rotates lazy susan

    # CLAW (4x MG90S):
    # {"cmd": "claw", "state": "open"} --------> opens all claw fingers
    # {"cmd": "claw", "state": "close", "force" : 0.5} ----------> close fingers with fsr sensors

    # SENSORS (4x FSR402)
    # {"cmd" : "fsr", "finger": 0} ==> returns {"fsr": 0, "value": 412} -----> reads 1 fsr sensor

    # EMERGENCY STOP:
    # {"cmd": "estop"} -----> stops all movement immediately

    # STOW (hardcoded safe position):
    # {"cmd": "stow"} ----------> go to safe stow position for the arm

    #PING
    # {"cmd": "ping"} ----------> returns {ORION ready, status: ok}

#PCA Channel MAP
#ch0 = MG996R tendon cable servo 0
#ch1 = MG996R tendon cable servo 1
#ch2 = MG996R tendon cable servo 2
#ch3 = MG996R lazy susan servo
#ch4 = MG90S claw finger servo 0
#ch5 = MG90S claw finger servo 1
#ch6 = MG90S claw finger servo 2

#RP2040 GPIO MAP
#GP4/GP5 - I2C0 SDA/SCL -> PCA9695
#gp26 = ADC0 -> FSR finger sensor 0
#gp27 = ADC1 -> FSR finger 1
#gp28 = ADC2 -> FSR finger 2
#usb = serial to pi 5

import sys
from Code.machine import Pin, I2C, ADC
import time
import json
import select


#PCA9685 I2C
PCA9685_ADDR = 0x40
I2C_SDA_PIN = 4 #gp4
I2C_SCL_PIN = 5 #gp5
I2C_FREQ = 400_000

#PCA9685 registers
PCA9685_MODE1 = 0x00
PCA9685_MODE2 = 0x01
PCA9685_LED0_ON_L = 0x06
PCA9685_PRESCALE = 0xFE

#Servo PWM
SERVO_MIN_US = 600 #0.6ms conservative minimum, safe for both mg90s and mg996r
SERVO_MAX_US = 2400 #2.4ms conservative max
#servo 90 deg = 1500 microseconds 
SERVO_FREQ_HZ = 50 
COUNTS_PER_US = 4096 / 20_000 #0.2048 counts per microsecond at 50hz

#ADC
FSR_ADC_PINS = [26, 27, 28] #gp26 = finger0, gp27 = finger1, gp28=finger2
ADC_MAX = 65535

#FSR
#forces 0-1.0 maps to adc values
FSR_MIN_THRESHOLD = 5000 #5000 = very light touch (0.25V)
FSR_MAX_THRESHOLD = 45000 #45000 = firm hard grip (2.27V)

#stow position
STOW_TENDON_ANGLES = [119, 52, 52]
STOW_CLAW_ANGLE = 180 # fully open
STOW_SUSAN_ANGLE = 90 #neutral

#claw closing parameters
CLAW_STEP_DEG = 2 #more precise the smaller it is
CLAW_STEP_DELAY_MS = 20
CLAW_TIMEOUT_S = 3.0 #hard timeout for if an fsr sensor doesnt trigger (in seconds)


#PCA9685 DRIVER

class PCA9685:
    #drives all 7 servos via I2C at 0x40
    #prescale = 121 -> 50.03 HZ (0.03HZ error which is negligable for servos)

    def __init__(self, i2c, addr=PCA9685_ADDR):
        self.i2c = i2c
        self.addr = addr
        self._init()
    
    def _write(self, address, val):
        self.i2c.writeto_mem(self.addr, address, bytes([val])) #could be bytearray change if using hashmap

    def _read(self, reg):
        return self.i2c.readfrom_mem(self.addr, reg, 1)[0]
    
    def _init(self):
        self._write(PCA9685_MODE1, 0x00)
        time.sleep_ms(10)

        #prescale -> round(25,000,000 / (4096 * frequnecy)) - 1
        #prescale at 50HZ round(25,000,000 / 204800 ) - 1 = 121
        prescale = round(25_000_000 / (4096 * SERVO_FREQ_HZ)) - 1
        prescale = max(3, min(255, prescale))

        mode1 = self._read(PCA9685_MODE1)
        self._write(PCA9685_MODE1, (mode1 & 0x7F) | 0x10) #sleep to change prescale
        self._write(PCA9685_PRESCALE, prescale) # change prescale
        self._write(PCA9685_MODE1, mode1)   #wake up
        time.sleep_ms(5)
        self._write(PCA9685_MODE1, mode1 | 0xA1) #autoincrement
        self._write(PCA9685_MODE2, 0x04) #totem pole output
        print(f"[PCA9685] Init OK - prescale = {prescale} (~{SERVO_FREQ_HZ}Hz)")

    def set_pwm(self, channel, on, off):
        #write raw on/off counts to one channel. on/off are 0-4095
        reg = PCA9685_LED0_ON_L + 4 * channel
        self.i2c.writeto_mem(
            self.addr, reg, bytes([on & 0xFF, on >> 8, off & 0xFF, off >> 8])
        )

    def set_servo_angle(self, channel, angle_deg):
        #set servo angle from 0-180
        #0 = 600, 90 = 1500, 180 = 2400
        angle_deg = max(0, min(180, int(angle_deg)))
        pulse_us = SERVO_MIN_US + (angle_deg / 180) * (SERVO_MAX_US - SERVO_MIN_US)
        off = int(pulse_us * COUNTS_PER_US)
        self.set_pwm(channel, 0, off)

    def all_off(self):
        #kill all pwm on each of the 16 channels (used for estop)
        for channels in range(16):
            self.set_pwm(channels, 0, 0) #servos will go limp

    #FSR sensors
class FSRSensors:
    #no touch = v-out becomes close to 0 volts
    #hard press = v out is close to v in
    #more force applied = higher ADC value
    #voltage divider - 3.3V -> FSR -> ADC pin -> 10k resistor -> GND

    def __init__(self):
        self.adcs = [ADC(Pin(pin)) for pin in FSR_ADC_PINS] #inits pins as ADC
        print(f"[FSR] Init Good - GP{FSR_ADC_PINS[0]}/GP{FSR_ADC_PINS[1]}/GP{FSR_ADC_PINS[2]}")

    def read(self, finger):
        #for each finger, read the raw ADC value (return 0-65535)
        if not 0 <= finger < len(self.adcs):
            return 0
        return self.adcs[finger].read_u16()
    
    def force_exceeded(self, finger, threshold):
        #return true if fsr reading is beyond threshold
        adc_threshold = int(FSR_MIN_THRESHOLD + threshold * (FSR_MAX_THRESHOLD - FSR_MIN_THRESHOLD))
        return self.read(finger) >= adc_threshold
    
 #servo controller
class ServoController:
    #servo control
    #tracks current position of all 7 servos
    #manages claw FSr feedback loop

    def __init__(self, pca, fsr):
        self.pca = pca
        self.fsr = fsr
        self.estop_flag = False #stow safety check

        #current position
        self.tendon_angles = [90, 90, 90]
        self.susan_angle = 90
        self.claw_angles = [180, 180, 180]

        self.stow()
        print(f"[SERVO] Stow complete")

        #tendons
    def set_tendon(self, cable, angle):
        #sets servo for 1 tendon
        if self.estop_flag:
            return
        angle = max(0, min(180, int(angle)))
        self.pca.set_servo_angle(cable, angle)
        self.tendon_angles[cable] = angle

    def set_all_tendons(self, angles):
        #sets servo for all tendons (same for all)
        for i, angle in enumerate(angles):
            self.set_tendon(i, angle)
    
    #lazy susan
    def rotate_susan(self, angle):
        #rotates servo for lazy susan
        if self.estop_flag:
            return
        angle = max(0, min(180, int(angle)))
        self.pca.set_servo_angle(3, angle)
        self.susan_angle = angle

    #claw
    def open_claw(self):
        #opens all 3 fingers fully
        if self.estop_flag:
            return
        for finger in range(3):
            self.pca.set_servo_angle(4 + finger, 180)
            self.claw_angles[finger] = 180
        print("[CLAW] Opened")

    def close_claw(self, force=0.5):
        #close all 3 fingers with per-finger fsr feedback
        #each finger stops independently when its own FSR threshold is hit
        #Hard timeout after claw timeout regardless

        #timing: 90 steps * 20ms = 1.8s max (which is within 3.0s timeout)

        if self.estop_flag:
            return
        
        force = max(0.0, min(1.0, float(force)))
        finger_complete = [False, False, False]
        current_angles = [180, 180, 180]
        start_time = time.time()
        print(f"[CLAW] Closing.. Force = {force}")

        while not all(finger_complete):
            if time.time() - start_time > CLAW_TIMEOUT_S:
                print("[CLAW] Timeout")
                break
        
            if self.estop_flag:
                break

            for finger in range(3):
                if finger_complete[finger]:
                    continue

                if self.fsr.force_exceeded(finger, force):
                    finger_complete[finger] = True
                    print(f"[CLAW] Finger {finger} FSR threshold reached")
                    continue

                new_angle = current_angles[finger] - CLAW_STEP_DEG
                if new_angle < 0:
                    finger_complete[finger] = True
                    continue

                self.pca.set_servo_angle(4 + finger, new_angle)
                current_angles[finger] = new_angle
                self.claw_angles[finger] = new_angle

            time.sleep_ms(CLAW_STEP_DELAY_MS)
        
        print(f"[CLAW] Final: {current_angles}")

    #stow
    def stow(self):
        #move to safe stow position
        #Order: open claw, center susan, fold tendons
        #has priority over estop, but clears estop flag first
        #total time is 1.1s (fits within Pi 2second connect delay)

        self.estop_flag = False #stow always works, even after estop

        print("[SERVO] Stowing..")

        #open claw (never stow while gripping an object)
        for finger in range(3):
            self.pca.set_servo_angle(4 + finger, STOW_CLAW_ANGLE)
        self.claw_angles = [STOW_CLAW_ANGLE] * 3
        time.sleep_ms(500)

        #center susan
        self.pca.set_servo_angle(3, STOW_SUSAN_ANGLE)
        self.susan_angle = STOW_SUSAN_ANGLE
        time.sleep_ms(300)

        #fold tendons (sleep is in loop to stagger for smoother movement)
        for i, angle in enumerate(STOW_TENDON_ANGLES):
            self.pca.set_servo_angle(i, angle)
            self.tendon_angles[i] = angle
            time.sleep_ms(100)

        print(f"[SERVO] Stowed - tendons = {STOW_TENDON_ANGLES} susan = {STOW_SUSAN_ANGLE}")

    #estop
    def emergency_stop(self):
        #cut all PWM channels so servos go limp
        #!!!(send stow command to recover)

        self.estop_flag = True
        self.pca.all_off()
        print("[SERVO] ESTOP - all channels off")

    #command handler
def handle_command(cmd_dict, servos, fsr):
        #Excecutes the parsed cmd dict
        #returns response to pi
        #No None return - all paths return something

        cmd = cmd_dict.get("cmd", "")

        if cmd == "ping":
            return {"status": "ok", "msg": "ORION firmware ready"}

        elif cmd == "tendon":
            cable = cmd_dict.get("cable")
            angle = cmd_dict.get("angle")
            if cable is None or angle is None:
                return {"status" : "error", "msg": "missing angle"}
            if not 0 <= int(angle) <= 180:
                return {"status" : "error", "msg": "angle must be between 0-180"}
            if not cable in (0, 1, 2):
                return {"status" : "error", "msg": "cable must be 0, 1, 2"}
            servos.set_tendon(int(cable), int(angle))
            return {"status": "ok", "angle": angle}
        
        elif cmd == "rotate":
            angle = cmd_dict.get("angle")
            if angle is None:
                return {"status" : "error", "msg": "missing angle"}
            if not 0 <= int(angle) <= 180:
                return {"status": "error", "msg": "angle must be between 0-180"}
            servos.rotate_susan(int(angle))
            return {"status" : "ok", "angle": angle}
        
        elif cmd == "claw":
            state = cmd_dict.get("state")
            if state == "open":
                servos.open_claw()
                return {"status" : "ok", "state" : "open"}
            elif state == "close":
                force = float(cmd_dict.get("force", 0.5))
                force = max(0.0, min(1.0, force))
                return {"status": "ok", "state": "closed", "force" : force}
            else:
                return {"status": "error", "msg": f"unknown claw state: {state}"}
            
        elif cmd == "fsr":
            finger = cmd_dict.get("finger", 0)
            if int(finger) not in (0, 1, 2):
                return {"status": "error", "msg": "finger must be 0, 1, or 2"}
            value = fsr.read(int(finger))
            return {"fsr" : finger, "value": value}
        
        elif cmd == "stow":
            servos.stow()
            return {"status": "ok", "msg": "stowed"}
        
        elif cmd == "estop":
            servos.emergency_stop()
            return {"status": "ok", "msg": "emergency stop activated"}
        
        else:
            return {"status": "error", "msg": f"unknown command: {cmd}"}
            
def send_response(response_dict):
        #send json response to pi over USB serial
        sys.stdout.write(json.dumps(response_dict) + "\n")

    #main
def main():
    print("ORION RP2040 Firmware")

    #init I2C
    i2c = I2C(0, sda = Pin(I2C_SDA_PIN), scl = Pin(I2C_SCL_PIN), freq = I2C_FREQ)

    #verify PCA9685 on bus
    devices = i2c.scan()
    print(f"[I2C] Found: {[hex(d) for d in devices]}")

    if PCA9685_ADDR not in devices:
        print(f"[ERROR] PCA9685 not found at {hex(PCA9685_ADDR)}")
        print("[ERROR] Check: SDA=GP4 SCL=GP5 VCC=3.3V GND=GND")
        while True:
            send_response({
                "status": "error",
                "msg": "PCA9685 not found - I2C wiring"
            })
            time.sleep(2)
    
    #init hardware
    pca = PCA9685(i2c)
    fsr = FSRSensors()
    servos = ServoController(pca, fsr)

    #pi serial_controller handshake ready
    print("[ORION] Ready")
    send_response({"status": "ok", "msg": "ORION firmware ready"})

    #setup serial poll
    poll = select.poll()
    poll.register(sys.stdin, select.POLLIN)
    
    #command loop
    buffer = ""

    while True:
        try:
            events = poll.poll(10)
            if not events:
                continue

            char = sys.stdin.read(1)
            if not char:
                continue

            if char in ("\n", "\r"):
                line = buffer.strip()
                buffer = ""

                if not line:
                    continue

                #parse JSON
                try:
                    cmd_dict = json.loads(line)
                except ValueError as e:
                    send_response({"status": "error", "msg": f"invalid JSON: {e}"})
                    continue

                #execute and respond
                try:
                    response = handle_command(cmd_dict, servos, fsr)
                    send_response(response)
                except Exception as e:
                    print(f"[ERROR] {e}")
                    send_response({"status": "error", "msg": str(e)})

            else:
                buffer += char
                #guard against runaway input
                if len(buffer) > 256:
                    print("[ERROR] Buffer overflow - clearing")
                    buffer = ""
            
        except KeyboardInterrupt:
            print("[ORION] Stopping - stowing arm")
            servos.stow()
            break

        except Exception as e:
            print(f"[LOOP ERROR] {e}")
            time.sleep_ms(100)
            #never crash the loop

if __name__ == "__main__":
    main()







                 



     






    

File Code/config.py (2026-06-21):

#detects platform automatically
#central config for ORION

import platform

#platform detection (PI or macOS)
is_pi = platform.machine() in ("aarch64" , "armv7l")
is_mac = platform.system() == "Darwin"

#ai models used
whisper_model = "tiny.en" if is_pi else "base"
ollama_model = "qwen2.5:3b-instruct"
ollama_url = "http://localhost:11434/api/generate"

#parser options
parser_options = {
            "temperature": 0.2, #changes temp to make it less sporadic (test 0.2 or 0.3)
            "top_p": 0.5,
            "num_predict": 100,
            "stop": ["\n\n", "---", "Voice command"]
}

#audio
SAMPLE_RATE = 16000
CHUNK_SIZE = 1280
CHANNELS = 1
SILENCE_THRESHOLD = 0.03
SILENCE_DURATION = 1.5
MAX_RECORD_DURATION = 10.0

#wake word stuff
wake_word = "hey_orion" if is_pi else "hey_jarvis"
wake_word_confidence = 0.5
wake_word_cooldown = 2.0

#usb serial port stuff
serial_port = "/dev/ttyACM0" if is_pi else None
serial_baud = 115200
serial_command = not is_pi #if on mac, print command, if on pi, send command

#hardware geometry
base_height = 76.2 #3inches in mm
pole_height = 203.3 #8 inches in mm (where camera will hang)
camera_height = pole_height + base_height #roughly 11 inches above the desk

#camera detection
detection_confidence = 0.5
priority_objects = {"person", "cell phone", "cup", "keyboard", "mouse", "book", "laptop"} #making a list of priority objects that it detects so it doesnt waste time on other stuff

name_mapping = {"person" : "person",
    "cell phone": "phone", #name mapping 
                "cup": "cup",
                "keyboard": "keyboard",
                "mouse": "mouse",
                "book": "book",
                "laptop": "laptop",
                }

#jsons
locations_file = "locations.json"

#multiprocessing
start_method = "fork" if is_pi else "spawn"

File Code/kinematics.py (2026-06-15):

#kinematics.py
#converts desk coords to motor commands for ORION
#breaks at extreme angles >60 degrees due to discrete joints
#constant curvature approximation for tendon driven continuum arm


import math

num_segments = 9
arm_length = 457.2 #1.5feet into mm
segment_length = arm_length / num_segments

base_height_mm = 76.2 #3inch base to mm

#servo stuff
servo_horn_radius = 27.0 #tune (needs to be atleast 27mm bc otherwise there cant be full RoM)
cable_mm_per_rad = servo_horn_radius

#new desk mount needs pretension to hold arm against gravity
servo_neutral = 75 #needs to be less than 90 (hanging mount neutral)
servo_max_pull = 75
servo_min = 0
servo_max = 180

#cable geometry
cable_angles_deg = [0.0, 120.0, 240.0]
cable_angles_rad = [math.radians(a) for a in cable_angles_deg]

max_cable_travel = cable_mm_per_rad * math.radians(servo_max_pull) #35.3mm (delta_L)

#lazy susan
lazy_susan_min = 0
lazy_susan_max = 180
lazy_susan_neutral = 90

#workspace limits
singularity = 20.0 #within 2cm of base = singularity

min_reach = 100.0 #10cm minimum
max_reach = arm_length * 0.95 #roughly 435mm (max before joints start being weird)

#constant curvature IK functions
def _solve_theta(horizontal_dist, arm_length, iterations=20):

    if horizontal_dist < singularity:
        return 0.0
    
    ratio = horizontal_dist / arm_length
    #clamp ratio
    ratio = min(ratio, 0.95)

    #guess
    theta = ratio * math.pi / 2

    for _ in range(iterations):
        if abs(theta) < 1e-6:
            break
        sin_t = math.sin(theta)
        cos_t = math.cos(theta)
        f = sin_t / theta - ratio
        df = (theta * cos_t - sin_t) / (theta ** 2)
        if abs(df) < 1e-10:
            break
        theta = theta - f / df
        theta = max(0.01, min(math.pi * 0.95, theta))
    
    return theta

def target_to_bend(horizontal_dist_mm):
    
    if horizontal_dist_mm < singularity:
        return 0.0, 0.0, 0.0
    
    horizontal_dist_mm = max(min_reach, min(horizontal_dist_mm, max_reach))

    phi = 0.0
    theta = _solve_theta(horizontal_dist_mm, arm_length)
    kappa = theta / arm_length if arm_length > 0 else 0

    return kappa, phi, theta

def bend_to_cable_lengths(kappa, phi, theta):
    #delta_l negative -> cable shortens = servo pulls = angle decreases from neutral
    #delta_l positive -> cable lengthens = servo releases = angle increases toward neutral
    
    cable_offset = 70.0 / math.sqrt(3) #roughly 40.4mm
    
    delta_lengths = []

    for alpha in cable_angles_rad:
        if abs(theta) < 1e-6:
            delta_l = 0.0
        else:
            delta_l = -cable_offset * theta * math.cos(phi - alpha)
        
        delta_lengths.append(delta_l)

    
    return delta_lengths

def cable_lengths_to_servo_angles(delta_lengths):

    angles = []

    max_delta = max(abs(d) for d in delta_lengths) if delta_lengths else 1.0
    #use scale factor so cable doesnt die if it exceeds travel limit
    scale = min(1.0, max_cable_travel / max_delta) if max_delta > 0 else 1.0

    for delta_l in delta_lengths:
        scaled = delta_l * scale
        angle = servo_neutral - (scaled / max_cable_travel) * servo_max_pull #could be servo_max (test)
        angle = max(servo_min, min(servo_max, int(angle)))
        angles.append(angle)

    return angles

#lazy susan function
def desk_to_lazy_susan(desk_x, desk_y):

    if abs(desk_x) < 0.1 and abs(desk_y) < 0.1:
        return lazy_susan_neutral
    
    angle_rad = math.atan2(desk_x, desk_y)
    angle_deg = math.degrees(angle_rad)

    servo_angle = int(lazy_susan_neutral + angle_deg)
    return max(lazy_susan_min, min(lazy_susan_max, servo_angle))

#main function

def desk_to_motor_functions(desk_x, desk_y):

    target_x = desk_x * 10.0
    target_y = desk_y * 10.0

    horizontal_dist = math.sqrt(target_x**2 + target_y**2)
    lazy_susan_angle = desk_to_lazy_susan(desk_x, desk_y)

    #handle singularity
    if horizontal_dist < singularity:
        return {
            "tendon_angles" : [servo_neutral] * 3,
            "lazy_susan_angle" : lazy_susan_neutral
        }
    
    kappa, phi, theta = target_to_bend(horizontal_dist)
    delta_lengths = bend_to_cable_lengths(kappa, phi, theta)
    tendon_angles = cable_lengths_to_servo_angles(delta_lengths)

    #normal stuff
    return {
        "tendon_angles" : tendon_angles,
        "lazy_susan_angle" : lazy_susan_angle
    }

#stow function because arm now needs to be angled at rest position to minimize torque by gravity
def stow_angles():
    
    stow_theta = math.radians(30) #30 degrees (tune)
    kappa = stow_theta / arm_length

    delta_lengths = bend_to_cable_lengths(kappa, 0.0, stow_theta)
    return cable_lengths_to_servo_angles(delta_lengths)

#testing

def test_kinematics():
    print("Desk Mounted Kinematics Test")

    print(f"Arm length: {arm_length}mm")
    print(f"Max reach: {max_reach}mm")
    print(f"Min reach: {min_reach}mm")
    print(f"Servo neutral: {servo_neutral}")
    print(f"Max cable delta_l: {max_cable_travel}mm\n")

    positions = [
        (0, 20, "forward 20cm"),
        (20, 20, "diagonal right 20cm"),
        (-20, 20, "diagonal left 20cm"),
        (0, 35, "max forward"),
        (25, 25, "far right diagonal"),
        (0, 0, "singularity"),
        (0, 5, "close range"), #clamps to 10cm
        (0, 43, "beyond max range"), #clamps to 43.4cm
        (0, -10, "behind base"),
        (20, 0, "only right"),
        (-20, 0, "only left"),
    ]


    for x, y, desc in positions:
        cmds = desk_to_motor_functions(x,y)
        print(f"Tendons: {cmds['tendon_angles']}")
        print(f"Lazy Susan: {cmds['lazy_susan_angle']}")

    print(f"Stow angles: {stow_angles()}")

if __name__ == "__main__":
    test_kinematics()

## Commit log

2026-06-12 Enhance README with additional project details
    Added details about sensors, rail system, and camera setup.
2026-06-12 serial_commands, hailo_detector, tri camera.py
2026-06-13 finish detector, multi_detector, half of kinematics
2026-06-15 TOOK OUT RAIL! kinematics finalized and massive debug
2026-06-19 Expand README with setup and installation instructions
    Added setup instructions including requirements, AI model installation, camera calibration, firmware flashing, and running the ORION project.
2026-06-21 3 usb camera not 2
2026-06-21 Organization and files
    [Angular E-Hub Connector x2.step, Angular Electronics Hub Connector x2.step, Base Camera Mount Mounter x1.step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]
2026-06-21 USB camera addition
2026-06-23 bom double check
    [BoM - Sheet1.csv, BoM.csv]
2026-06-23 Fix spelling errors in 3D printing instructions
    Corrected spelling errors in the README.
2026-06-23 file cleanup
    [Angular E-Hub Connector x2.step, Base Camera Mount x1.step, Camera mount x2.step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]
2026-06-23 bom edit
    [BoM.csv, Overhead Camera Mount x1.step]
2026-06-24 removed spaces
    [Angular_E-Hub_Connector_x2.step, Base_Camera_Mount_x1.step, BoM.csv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]
2026-06-24 Revise README to improve structure and clarity
    Reorganized the introduction and added a new section about the problem ORION addresses. Enhanced clarity and flow of the README content.
2026-06-24 Revise README for clarity and additional details
    Updated README with build and run guide, wiring information, and BOM list.
2026-06-26 Add large Autodesk Fusion f3z file using Git LFS
    [Full_ORION.f3z]
